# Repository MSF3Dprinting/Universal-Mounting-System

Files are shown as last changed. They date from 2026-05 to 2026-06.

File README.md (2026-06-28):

# 3D printed product technical specification datasheet

## General Information

| Field | Value |
|---|---|
| Internal Ref. | N/A |
| Name | Universal Mounting system  |
| Product stage | Product in development |

## FORM

### Product picture

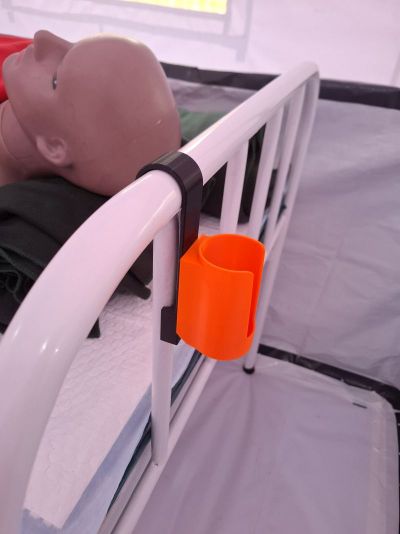
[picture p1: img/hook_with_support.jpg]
Humidifier holder using hook with support attached to hospital bed


### Version / Category / Subcategory / Critical item / Dangerous goods / Short description

- Version: 1.0
- Category: Medical
- Subcategory: Biomed
- Critical item: Yes
- Dangerous goods: No
- Short description: Universal Mounting System V1 (UMS V1) is set of mutually compatible attachments, hooks, holders and clamps used to mount various devices and accessories on the wall, beds and other objects in the hospital environment. The UMS allows easy attachment, removal, changing of the devices and cleaning. 

### Dimensions / Use / Solution type

- Overall dimensions: N/A
- Single/Multiple use: Multiple use item
- Permanent/Temporary solution: Context dependent

### License

- License: MIT

### Readiness

- Field readiness: 4
- Maker readiness: 5
- User readiness: 4
- Technology readiness: 4
- Risk level: 3

### Justification of using 3D printed item

In low-resource hospital settings, limited access to standard accessories makes it difficult to properly arrange and attach medical devices, resulting in equipment damage decrease of lifespan, improper use and IPC issues. 3D printing enables local production of custom solutions enabling users to safely mount the equipment in a suitable position and location.

### Approval required by

- Biomed advisor, IPC advisor

## FIT

### Compatibility

#### Primary compatibility:

Back parts:

- Double hook extended: Hospital bed with back rest- diameter of the round horizontal tube: 32mm , Trolley - diameter of the round horizontal tube: 19mm 
- Single Hook: Diameter of round horizontal tube: 25mm
- Wall mount with safety lock: Any wall surface
- Hook with support - used for the hospital bed with bed rest attached using zip tie for more stable position: 32mm diameter of round horizontal tube
- Vertical pole attachment for pole diameter 20 and 25mm

Front parts:

- Humidifier bottle holder 49mm: Bottle diameter 49mm
- Humidifier bottle holder 56mm: Bottle diameter 56mm
- Pulse oximeter hodler: Massimo pulse oximeter handheld
- Ultrasound transducer holder: Abdominal transducer

#### Compatible accessories:

Back parts:
- Wall mount with safety lock - M5 bolts or screws with diameter 4-5mm
- Hook with support, vertical pole attacments- 5mm zip tie

### Manufacturing Instructions

#### 3D printing optimization
##### Bottom edges are chamfered
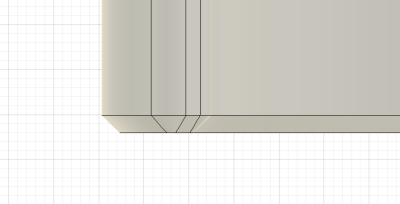
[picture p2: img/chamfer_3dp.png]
Bottom edge is chamfered

##### Horizontally prited holes are optimized for 3D printing
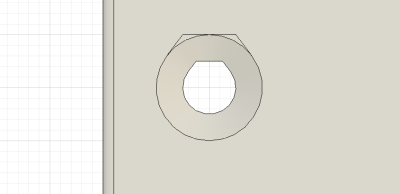
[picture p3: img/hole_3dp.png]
Horizontally printed holes are optimized for 3D printing

##### In-built supports are included where needed
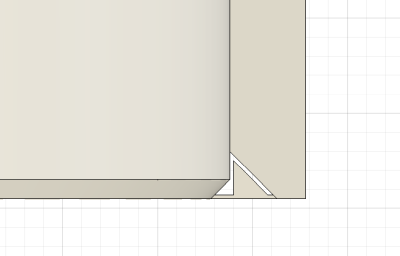
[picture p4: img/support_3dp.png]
In-built supports are included


#### Material and color

- PETG White, Natural or Light Color so it is clearly visible if the item needs cleaning or has any surface imperfections.

#### List of other materials

- N/A

#### 3D Printer

- 3D Printer:  Any FDM 3D printer

#### Slicer settings

- General settings: 0.2mm layer height, 3-5 perimeters for increased strength, no supports
- Hooks, back part: brim is recommended for better stability and adhesion during printing

#### Post processing instructions

- Remove the brim if printed with brim
- Clean the surface from stringing and other imperfections
- Use deburring tool to clean the sharp edges

#### Assembly instructions

- After installation of the back part, slide the appropriate front part.
- Clean using the recommended cleaning methods before use

#### QC procedures

- Visual inspection: Ensure the surface does not have printing artifacts, strining and misaligned layer lines. Surface should be smooth.
- Dimensional validation: Check if the back and front parts fit into each other before installation. Ensure that the respective device (e.g. humidifier bottle) fits into the holder before installation. The device should always hold in a stable manner and should be easily removable.
- Tolerance inspection: The back and front part should slide easily but hold firmly.
- Safety validation: Validate with respective advisors before use.
- Regular product check frequency and responsibility: Weekly check after installation recommended. Focus on cracks in the 3D printed body, surface cleaniness and mechanical flexibility of the latches and hooks (the material can become brittle after time)

## FUNCTION

### Detailed description of the component/product/workflow and its use

Universal Mounting System V1 (UMS V1) is set of mutually compatible attachments, hooks, holders and clamps used to mount various devices and accessories on the wall, beds and other objects. The UMS allows easy attachment, removal and changing of the devices. Each holder consist of the back part and front part. Back part is attached either to the bed, pole or wall, while the front part slides into the back part and holds the device it is designed for. The front and back parts are always mutually compatible. So it can be used interchageably. 

### Additional notes

- N/A

### Cleaning and disinfection / sterilization procedures

- Use Surfanios, Bleach 1:10 or Ethanol 70% to clean the surface, follow relevant IPC guidelines.
- Do not use autoclave.

### Packaging and storing instructions

- After production pack in a sealable zip lock bags.
- Store in room temperature, do not expose to direct sunlight or humidity.

### Related links, standards, safety considerations

- Do not put any text or embossed symbols due to surface cleaning.

### Spaulding Classification (IPC)

- To be added

## ATTACHMENTS

- N/A

| Role | Name | Date |
|---|---|---|
| Designed by | Silvestr Tkac | Date: 11/05/2026 |
| Product approved by |  | Date: |
| Product tested by |  | Date: |

## VERSION HISTORY

| Version | Date modified | Modified by | Changes |
|---|---|---|---|
| 1.0 | 11/05/2026 | Silvestr Tkac | Initial documentation |
|  |  |  |  |
|  |  |  |  |
|  |  |  |  |
|  |  |  |  |
|  |  |  |  |
|  |  |  |  |
|  |  |  |  |

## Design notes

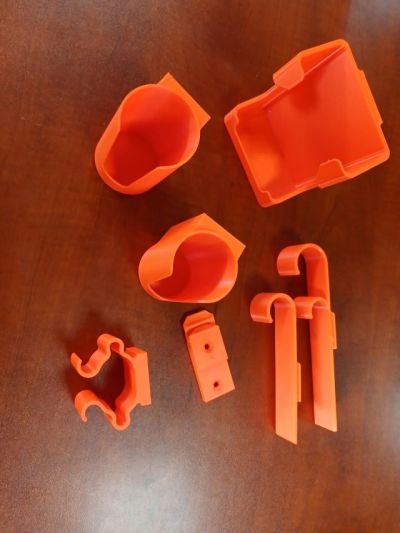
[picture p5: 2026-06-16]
img/image.jpg

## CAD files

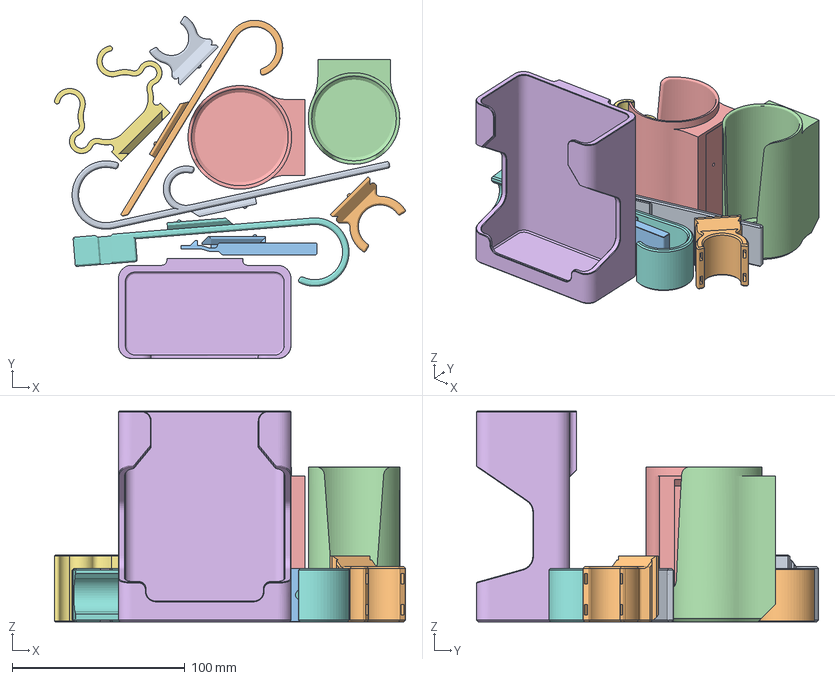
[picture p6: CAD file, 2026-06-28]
3D files/3MFs/UMS set.3mf
203.3 x 198.2 x 122.0 mm
Double hook extended.stl
Single hook.stl
Wall mount with safety lock.stl
Humidifier bottle holder - 49mm.stl
Humidifier bottle holder - 56mm.stl
Pulse oximeter holder.stl
Ultrasound transducer holder.stl
Double hook extended - with support.stl
Vertical attachment 20mm.stl
Vertical attachment 25mm.stl

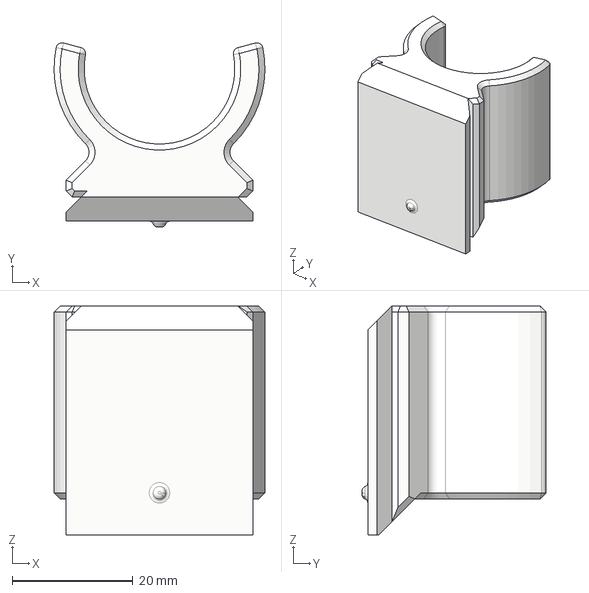
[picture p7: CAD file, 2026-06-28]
3D files/STEP/Back parts/Vertical attachment 25mm.step
35.0 x 30.6 x 38.0 mm

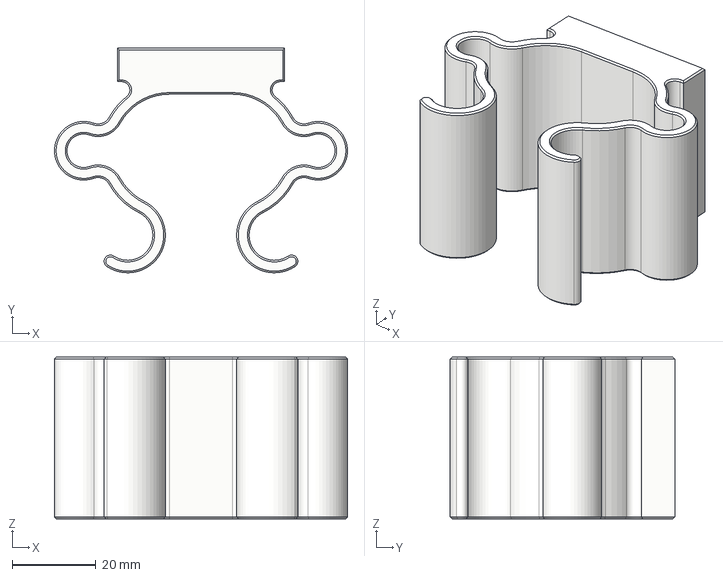
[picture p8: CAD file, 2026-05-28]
3D files/STEP/Front parts/Ultrasound transducer holder.step
70.0 x 53.7 x 38.6 mm

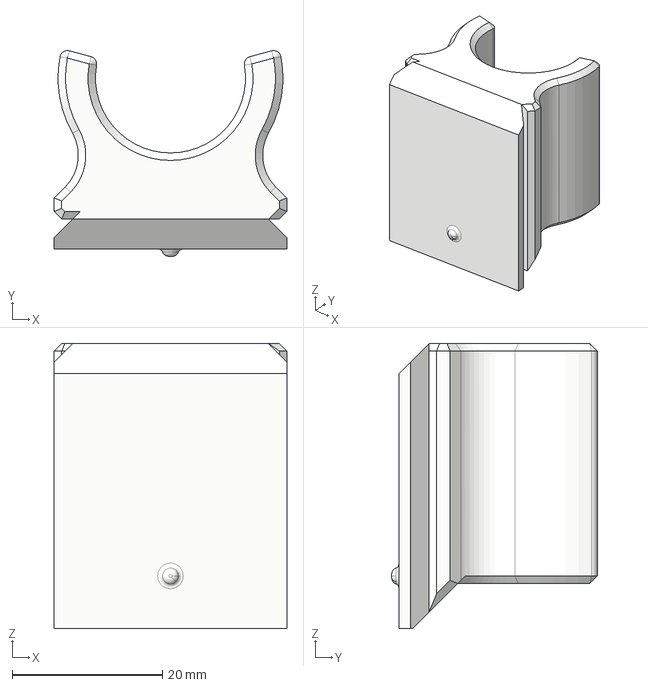
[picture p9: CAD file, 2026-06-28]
3D files/STEP/Back parts/Vertical attachment 20mm.step
31.0 x 27.4 x 38.0 mm

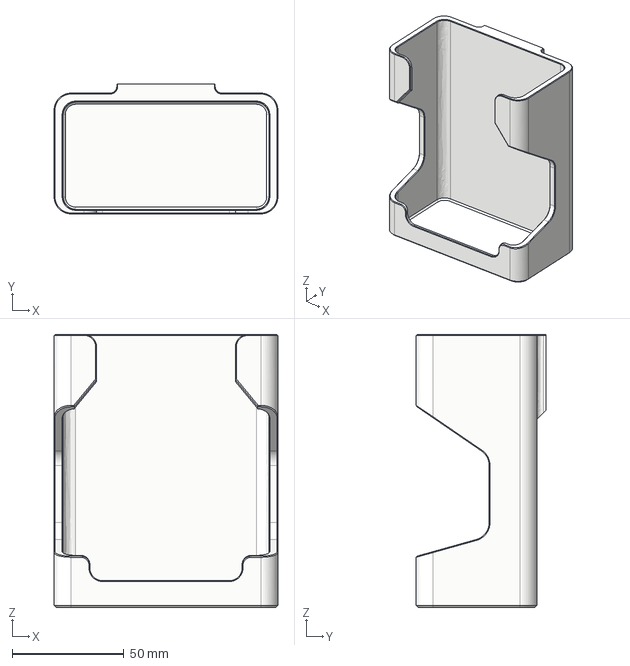
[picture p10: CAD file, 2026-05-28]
3D files/STEP/Front parts/Pulse oximeter holder.step
100.0 x 58.0 x 122.0 mm

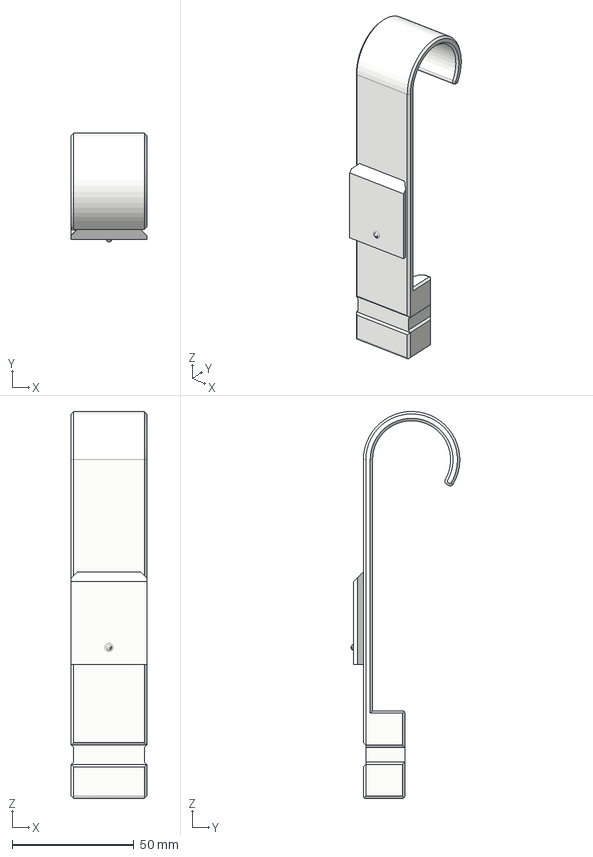
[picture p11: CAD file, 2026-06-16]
3D files/STEP/Back parts/Hook with support.step
31.0 x 44.6 x 158.8 mm

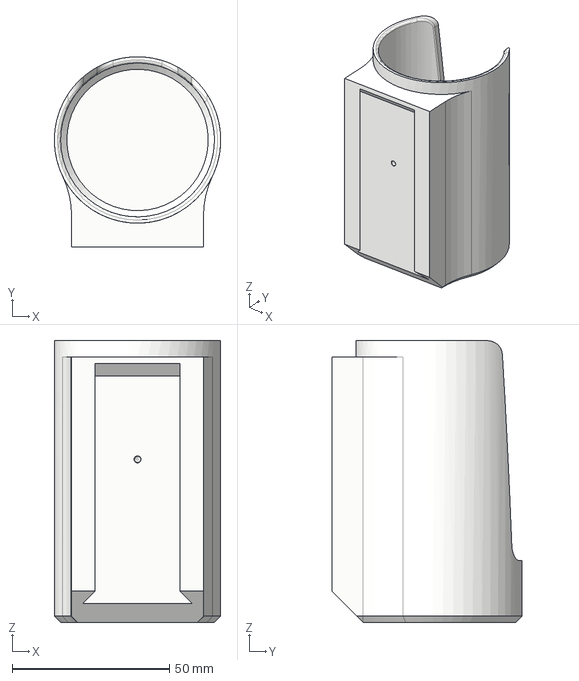
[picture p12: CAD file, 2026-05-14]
3D files/STEP/Front parts/Humidifier bottle holder - 49mm.step
53.0 x 60.6 x 89.8 mm

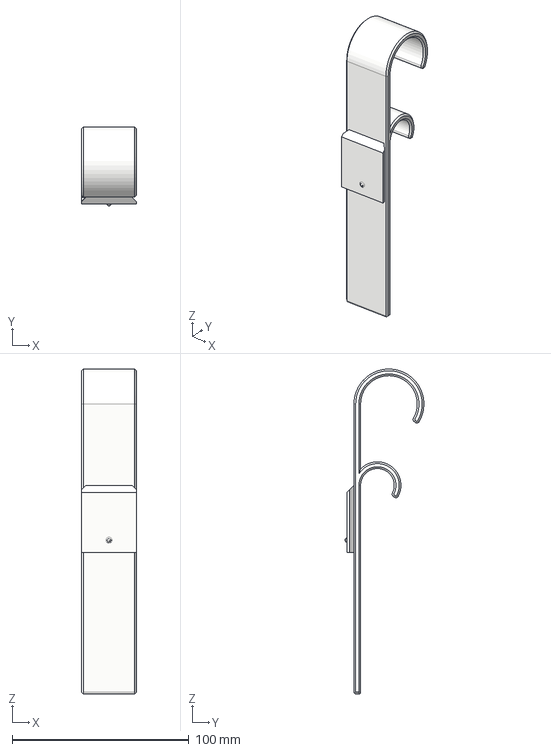
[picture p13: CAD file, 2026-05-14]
3D files/STEP/Back parts/Double hook extended.step
31.0 x 44.6 x 183.8 mm

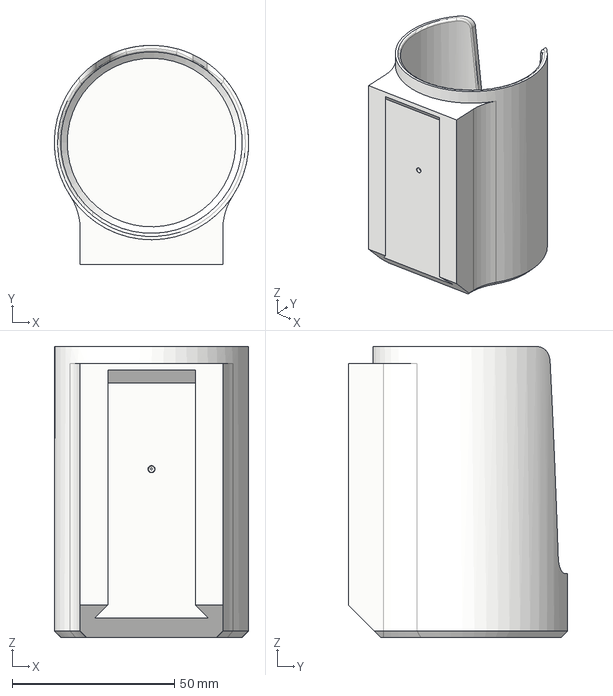
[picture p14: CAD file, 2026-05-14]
3D files/STEP/Front parts/Humidifier bottle holder - 56mm.step
60.0 x 67.6 x 89.8 mm

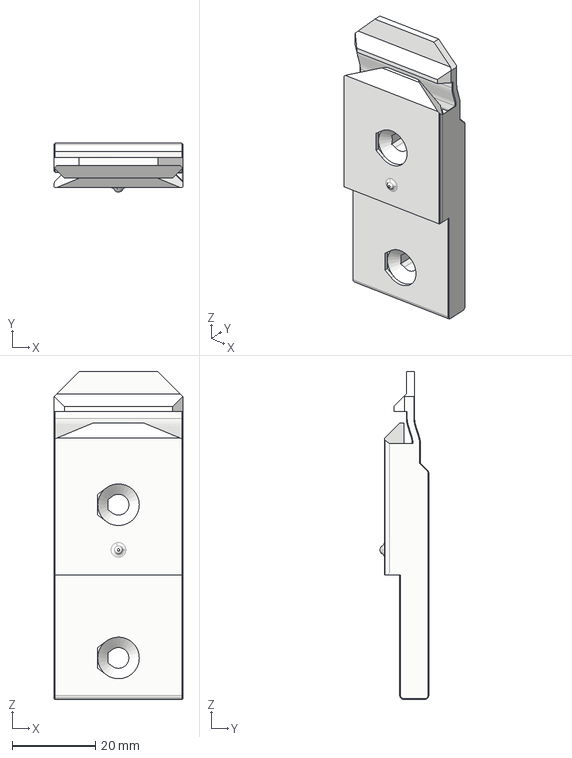
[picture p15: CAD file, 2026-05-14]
3D files/STEP/Back parts/Wall mount with safety lock.step
31.0 x 11.7 x 78.9 mm

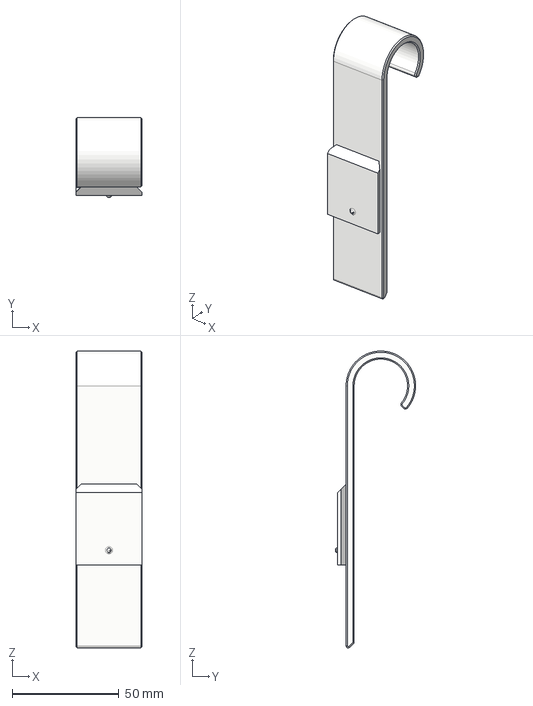
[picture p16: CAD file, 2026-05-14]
3D files/STEP/Back parts/Single hook.step
31.0 x 37.6 x 139.1 mm

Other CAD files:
3D files/STLs/Back parts/Double hook extended.stl
3D files/STLs/Back parts/Hook with support.stl
3D files/STLs/Back parts/Single hook.stl
3D files/STLs/Back parts/Vertical attachment 20mm.stl
3D files/STLs/Back parts/Vertical attachment 25mm.stl
3D files/STLs/Back parts/Wall mount with safety lock.stl
3D files/STLs/Front parts/Humidifier bottle holder - 49mm.stl
3D files/STLs/Front parts/Humidifier bottle holder - 56mm.stl
3D files/STLs/Front parts/Pulse oximeter holder.stl
3D files/STLs/Front parts/Ultrasound transducer holder.stl

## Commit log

2026-05-14 Adding 3D models
    [Double hook extended.step, Double hook extended.stl, Humidifier bottle holder - 49mm.step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]
2026-05-14 Adjusting hooks
    [Double hook extended.step, Double hook extended.stl, Hook Universal.step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]
2026-05-28 Adding ultrasound transducer and pulse oximeter hodler
    [Pulse oximeter holder.step, Pulse oximeter holder.stl, Ultrasound transducer holder.step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]
2026-05-28 Rarranging directories
    [Double hook extended.step, Double hook extended.stl, Hook Universal.step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]
2026-06-02 Adding 3mf and gcode for the UMS set
    [UMS set.3mf]
2026-06-16 Adding hook with support
    [Hook with support.step, Hook with support.stl, UMS set.3mf]
2026-06-28 Adding vertical poles attachments
    [Vertical attachment 20mm.step, Vertical attachment 20mm.stl, Vertical attachment 25mm.step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]
2026-06-28 Adding 3mf and gcode with new models
    [UMS set.3mf]
